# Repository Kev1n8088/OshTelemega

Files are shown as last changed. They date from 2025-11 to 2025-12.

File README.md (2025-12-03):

# Mega3080 v1.0

The Mega3080 FCU is an evolved clone of the Altus Metrum Telemega. Using the same firmware (meaning the same sensor suite), the primary developments are:
- USB-C
- Wago style spring terminals
- Better GPS RF routing, and external GPS antenna
- Companion port with extra UART and space for potential direct Mosaic Integration
- Mag switch with "hard to disarm" feature 
- Slightly smaller (30x80mm instead of 31.25x82.55mm)
- Better reverse polarity protection, including on pyro charges
- Cheaper than purchasing a TeleMega

## Basic Manual

All Wago ports are the same as the Telemega screw terminals, except for the addition of a connector to select between an external switch and the internal mag switch (you can use both!).

To enable the internal mag switch, bridge the terminals marked **MG**. A magnet's **N** pole perpendicular to the top surface magnetic sensor (under the square buzzer) arms the device. 

A fully armed device has the dual-LED next to the mag sensor fully lit (green and red). To begin the disarm process, expose the sensor to a **S** pole, then a **N** pole, and then an **S** pole. This will cycle the LED lights. This feature prevents any risk of disarming from launch towers that may generate magnetic fields.

If a device on the pad has a partially lit LED, the disarm process has started. It is recommended that a disarm and arming cycle be completed to reduce the risk of inadvertent disarm; however, even during the disarm process, the device remains as, if not less, sensitive to stray magnetic fields as industry-standard altimeters.

To use an external switch, simply wire it in series with the terminals marked **SW**. 

If you want an external switch in parallel with the internal mag switch **(NOT RECOMMENDED)** - you can wire both a switch in series with the **SW** terminals, and bridge the **MG** terminals. 

If you want an external switch in series with the internal mag switch **(MAYBE ALRIGHT?)** - you can wire a switch in series with the **MG** terminals. 

To enable GPS operation, connect a standard L1 patch antenna to the rear UFL connector marked L1 GPS. This port supports both passive and active patch antennas. 

Companion and servo connector documentation TBD

See the `flashing.md` file for flashing info. 

## Production
All SMT components can be assembled via JLCPCB.

THT BOM is to be produced soon. 

Use the `jlcpcb/production_files` subdirectory for production files. I do not guarantee that everything will be in stock on JLC, nor do I guarantee that the rotations are correct (they are not, **CHECK VERY CAREFULLY!**).

Recommended configuration is **JLC04161H-7628**. I recommend ENIG, but it's likely not necessary. 

## Notes
Use at your own risk! This device has not been validated as of Dec 2025, and custom production from JLC always carries the risk of QC issues. 

You must provide your own patch antenna (preferably active) to use the GPS

There are a few minor issues known with the v1.0 model: 

- When powered through the mag switch, there is a diode in the path for pyro power. This shouldn't be an issue in practice, but it is technically rated only for 1A continuous. The transient rating is more than enough at 50A, so it's not really a huge issue. There is also a slight voltage drop. Not an issue when the mag switch is bypassed or when a separate pyro battery is used.
- Theoretically, the vertical USB-C Connector is more fragile than a horizontal one - and also harder to solder with a hot air station. Take care when using heavy cables, and if you are concerned, epoxy the connector down.
- Due to a technical oversight, the separate pyro battery capability of the stock telemega, which is rated up to 30v, has to be derated to 12v on the Mega3080. Not sure how many people use a 12+v external pyro battery, but something to be aware of.

The v1.1 release has fixed the USB-C issue; however, the v1.1 device has not been produced yet. Use at your own risk.  

---

**Device Version Last Produced Officially:** v1.0

**Last Updated:** December 2025  

**Written by:** Kevin Zheng (Kev1n8088)

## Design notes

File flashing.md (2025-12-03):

# Building TeleMega v7.0 Bootloader on Windows

This guide shows how to build the bootloader firmware for TeleMega v7.0 using Windows Subsystem for Linux (WSL). After the bootloader is installed once via ST-Link, all future firmware updates can be done through AltosUI over USB. 

This procedure should be identical for all other USB-flashed Altus Devices, just with a different ```src``` subdirectory - but this has not been tested by the author. 

## Prerequisites

- Windows 10/11 with WSL support
- ST-Link programmer (for initial bootloader flash only)
- Blank STM32L1 chip on TeleMega v7.0 board
- STM32 ST-Link Utility installed on Windows
- AltOS Software installed
- AltOS Source downloaded - from [here](https://altusmetrum.org/AltOS/)

## Step 1: Install WSL Ubuntu

Open PowerShell as Administrator and run:

```powershell
wsl --install -d Ubuntu-24.04
```

Restart your computer when prompted, then launch Ubuntu from the Start menu and create a user account.

## Step 2: Install Build Dependencies

In the Ubuntu terminal:

```bash
sudo apt update
sudo apt install -y gcc-arm-none-eabi build-essential autoconf automake \
    libtool picolibc-arm-none-eabi default-jdk libjansson-dev nickle
```

## Step 3: Copy Source to WSL

Copy the AltOS source to WSL's native filesystem (required to avoid NTFS permission issues):

```bash
cp -r /mnt/c/Users/<YourUsername>/Desktop/altos-1.9.22 ~/altos-1.9.22
cd ~/altos-1.9.22
```

Replace `<YourUsername>` with your Windows username.

## Step 4: Configure Build System

```bash
./configure --with-arm-cc=arm-none-eabi-gcc
```

This will check for all required dependencies and configure the build system.

## Step 5: Build the Bootloader

```bash
cd src/telemega-v7.0/flash-loader
make
```

The bootloader will be built as:
- `telemega-v7.0-altos-flash-1.9.22.elf` (ELF binary)
- `telemega-v7.0-altos-flash-1.9.22.hex` (Intel HEX format for ST-Link)

Verify the build succeeded:

```bash
ls -lh telemega-v7.0-altos-flash-1.9.22.*
```

You should see both `.elf` and `.hex` files (~4KB each).

## Step 6: Copy Bootloader to Windows

```bash
cp telemega-v7.0-altos-flash-1.9.22.hex /mnt/c/Users/<YourUsername>/Desktop/
```

## Step 7: Flash Bootloader with ST-Link

1. Connect ST-Link programmer to TeleMega v7.0 SWD interface:
   - **SWDIO** → SWDIO
   - **SWCLK** → SWCLK
   - **GND** → GND
   - **3.3V** → 3v3
   - Make sure the board is powered by a seperate power supply as the ST-Link Programmer does not provide power.

2. Open **STM32 ST-Link Utility** on Windows

3. Click **Target → Connect**

4. Click **Target → Program & Verify...**

5. Browse to `telemega-v7.0-altos-flash-1.9.22.hex` on your Desktop

6. Click **Start**

7. Wait for "Verification...OK" message

8. Disconnect ST-Link programmer

## Step 8: Flash Main Firmware via AltosUI

1. Connect TeleMega v7.0 to PC via USB

3. Launch **AltosUI**

4. Click **Flash Image**

5. Select serial port (e.g., COM13)

6. Browse for the Telemega 7.0 flight firmware in the AltosMetrum file directory - look for something named ```telemega-v7.0-1.9.22.ihx``` or similar

7. Click **OK** to flash

8. Wait for completion message

9. Device will reboot into main firmware

## Step 9: Initial Configuration

Conduct the standard initialization procedure in AltOS, including accelerometer calibration - this should clear the "Sensor failure" beeps. Add your callsign, configure deployments, and calibrate the radio (TBD)

## Memory Map Reference

- **Bootloader:** `0x08000000` - `0x08001000` (4KB)
- **Main Firmware:** `0x08001000` - `0x08020000` (124KB)

## Troubleshooting

### Build Errors

**"No JVM files found" during configure:**
- Java is required even though it's not used for bootloader
- Install: `sudo apt install default-jdk`

**Permission denied errors:**
- Ensure source is in `~/altos-1.9.22` (WSL filesystem)
- Don't build from `/mnt/c/` (NTFS mounts have permission issues)

**Missing picolibc:**
- Install: `sudo apt install picolibc-arm-none-eabi`

### Flashing Issues

**ST-Link cannot connect:**
- Check SWD wiring (SWDIO, SWCLK, GND)
- Verify board has power (LED should be on)
- Try "Connect under reset" option in ST-Link Utility

**Device not recognized by AltOS after bootloader flash:**
- Attempt a power cycle. 
- If not functional, do not panic - try to reflash the bootloader **OR:** 
- Follow the recovery procedure of connecting the Companion port CS0 (pin 6) to GND when powering the device on to force it into recovery mode.  

**COM port not visible:**
- Install Altus Metrum drivers (included with AltosUI)
- Check Device Manager for unrecognized devices
- Manually install `altusmetrum.inf` if needed

**Sensor failure beeps (dah dit dit dah):**
- Run accelerometer calibration in AltOS
- If not fixed, confirm all sensors operation in Serial terminal by opening the COM port and sending in the ```?``` command at 115200 baud for the commands required for querying sensors. Note that for some reason this COM port does not show up in the VSCode for some reason - it worked for on PuTTY for the author. 

## Future Firmware Updates

After the bootloader is installed, **ST-Link is no longer needed**. All future updates can be done via USB:

1. Connect device via USB
2. Launch AltosUI
3. Click **Flash Image**
4. Select your device and new firmware file
5. Flash completes automatically

## Notes

- The bootloader only needs to be flashed **once per board**
- Standard `telemega-v7.0` firmware is for normal flight operations
- `telemega-v7.0-seeed` variant is for hardware validation only (requires GPS lock in 10 seconds)
- Always calibrate accelerometer before first flight
- Firmware version 1.9.22 includes Mosaic X5 GPS support (configurable via `c g` command)

## Additional Resources

- AltOS Documentation: https://altusmetrum.org/AltOS/doc/
- Source Repository: https://altusmetrum.org/AltOS/

---

**Version:** 1.9.22  
**Last Updated:** December 2025  
**Target Hardware:** TeleMega v7.0 (STM32L1 series)

**Written by:** Kevin Zheng (Kev1n8088)

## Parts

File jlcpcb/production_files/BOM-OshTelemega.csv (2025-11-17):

Comment | Designator | Footprint | LCSC | Quantity
1.8nF | C27 | C_0402_1005Metric | C107024 | 1
DFLS130L | D1 | D_PowerDI-123 | C110493 | 1
56k | R11,R12 | R_0402_1005Metric | C114756 | 2
1k | R17,R20,R22,R26,R3,R30,R34,R38,R39,R4,R50,R51,R56 | R_0402_1005Metric | C11702 | 13
CC1200 | U8 | QFN-32-1EP_5x5mm_P0.5mm_EP3.45x3.45mm | C122881 | 1
LQG15HS22NG02D | L8 | L_0402_1005Metric | C12670 | 1
BATT | J8 | JST_PH_B2B-PH-K_1x02_P2.00mm_Vertical | C131337 | 1
STM32L151VCTx | U1 | LQFP-100_14x14mm_P0.5mm | C1338621 | 1
5.6k | R46 | R_0402_1005Metric | C137856 | 1
2.49k | R37 | R_0402_1005Metric | C145071 | 1
MCP73831-2-OT | U17 | SOT-23-5 | C14879 | 1
10nF | C22,C33,C35,C43 | C_0402_1005Metric | C15195 | 4
0.1uF | C1,C10,C16,C17,C3,C4,C44,C7,C9 | C_0402_1005Metric | C1525 | 9
100pF | C36 | C_0402_1005Metric | C1546 | 1
8pF | C5,C6 | C_0402_1005Metric | C1549 | 2
10uF | C18 | C_0402_1005Metric | C15525 | 1
6.2pF | C42 | C_0402_1005Metric | C161332 | 1
56pF | C31 | C_0402_1005Metric | C162113 | 1
LQG15HS56NJ02D | L1,L2 | L_0402_1005Metric | C162544 | 2
ECS-160-8-36Q-AES-TR1 | X2 | Crystal_SMD_2520-4Pin_2.5x2.0mm | C1669787 | 1
0.22uF | C13 | C_0402_1005Metric | C16772 | 1
LED_Dual_AAKK | D3,D4,D5 | DualLED0606 | C183840 | 3
BMI088 | U9 | Bosch_LGA-16_4.5x3mm_P0.5mm_LayoutBorder7x1y_ClockwisePinNumbering | C194919 | 1
WE-TVS-82400102 | U2 | SOT-23-6 | C1975330 | 1
MLG1005S43NJTD25 | L7 | L_0402_1005Metric | C2042359 | 1
AO3400A | Q2 | SOT-23 | C20917 | 1
SISB46DN | U20,U22,U23 | PowerPak1212-8-Dual | C22366987 | 3
8.06k | R41 | R_0402_1005Metric | C227258 | 1
4.7uF | C20,C21 | C_0402_1005Metric | C23733 | 2
10R 0.25W | R54 | R_0402_1005Metric | C25077 | 1
18 | R48 | R_0402_1005Metric | C25084 | 1
220 | R5,R6,R7,R8 | R_0402_1005Metric | C25091 | 4
22 | R10,R9 | R_0402_1005Metric | C25092 | 2
CPE-171 | U11 | XDCR_CPT-7502-65-SMT-TR | C25504047 | 1
ABM8W-40.0000MHZ | Y1 | Crystal_SMD_Abracon_ABM8G-4Pin_3.2x2.5mm | C255943 | 1
100k | R13,R14,R23,R27,R31,R35,R44,R49,R52,R53 | R_0402_1005Metric | C25741 | 10
10k | R40,R42,R47 | R_0402_1005Metric | C25744 | 3
12k | R15,R16,R24,R28,R32,R36,R45 | R_0402_1005Metric | C25752 | 7
3.3k | R18,R19,R21,R25,R29,R33 | R_0402_1005Metric | C25890 | 6
5.1k | R1,R2 | R_0402_1005Metric | C25905 | 2
DRV5012AEDMRR | U7 | Texas_X2SON-4-1EP_1.1x1.4mm_P0.5mm_EP0.8x0.6mm | C2655038 | 1
LI0402C221R-10 | FB1 | L_0402_1005Metric | C269768 | 1
9.09k | R43 | R_0402_1005Metric | C274897 | 1
UFL | J5 | U.FL_Molex_MCRF_73412-0110_Vertical | C277719 | 1
TC2185-3.3VxCTTR | U18 | SOT-23-5 | C2798212 | 1
5.1pF | C37,C38,C39 | C_0402_1005Metric | C281761 | 3
USB_C_Receptacle_USB2.0_16P | J4 | USB_C_Receptacle_G-Switch_GT-USB-7051x | C2843970 | 1
SERVOS | J10 | PinHeader_2x03_P1.27mm_Vertical | C2935951 | 1
Conn_02x05_Counter_Clockwise | J9 | PinHeader_2x05_P1.27mm_Vertical | C2935954 | 1
W25Q64JVXGIQ | U19 | DFN_XGIQ TR_WIN | C2940195 | 1
LM293QT | U12,U13,U15 | DFN-8-1EP_2x2mm_P0.5mm_EP0.9x1.6mm | C2970217 | 3
39pF | C40 | C_0402_1005Metric | C327068 | 1
10pF | C25,C26 | C_0402_1005Metric | C32949 | 2
PPS | D6 | LED_0402_1005Metric | C364550 | 1
MMC5983MA | U10 | LGA-16_3x3mm_P0.5mm | C404329 | 1
MAX-M10S | U5 | ublox_MAX | C4153167 | 1
SN74LVC1G80QDCKTQ1 | U21 | SOT-353_SC-70-5 | C473331 | 1
ADXL375 | U3 | LGA-14_3x5mm_P0.8mm_LayoutBorder1x6y | C481898 | 1
1uF | C19,C2,C24,C8 | C_0402_1005Metric | C52923 | 4
LQG15HZ27NJ02D | L3,L4 | L_0402_1005Metric | C560069 | 2
47nF | C11,C12,C14,C15,C28,C29,C30,C32,C34 | C_0402_1005Metric | C576715 | 9
100k | R55 | R_0402_1005Metric | C60491 | 1
MCP130-xxxxTT | U6 | SOT-23 | C625194 | 1
SiA449DJ | Q1,Q3,Q4 | Vishay_PowerPAK_SC70-6L_Single | C727325 | 3
BAT54CW | D2 | SOT-323_SC-70 | C82467 | 1
LQG15HS15NJ02D | L5,L6 | L_0402_1005Metric | C86059 | 2
2.2pF | C41 | C_0402_1005Metric | C88887 | 1
47uF | C23 | C_1206_3216Metric | C96123 | 1
MS5607-02BA | U4 | LGA-8_3x5mm_P1.25mm | C97627 | 1
LQG15HS47NJ02 | FB2 | L_0402_1005Metric | C97998 | 1
RIGHT | J6 | CONN9_250-309_WAG |  | 1
LEFT | J7 | CONN9_250-309_WAG |  | 1
SMA_Edgelaunch | J3 | SMA_Amphenol_132289_EdgeMount |  | 1

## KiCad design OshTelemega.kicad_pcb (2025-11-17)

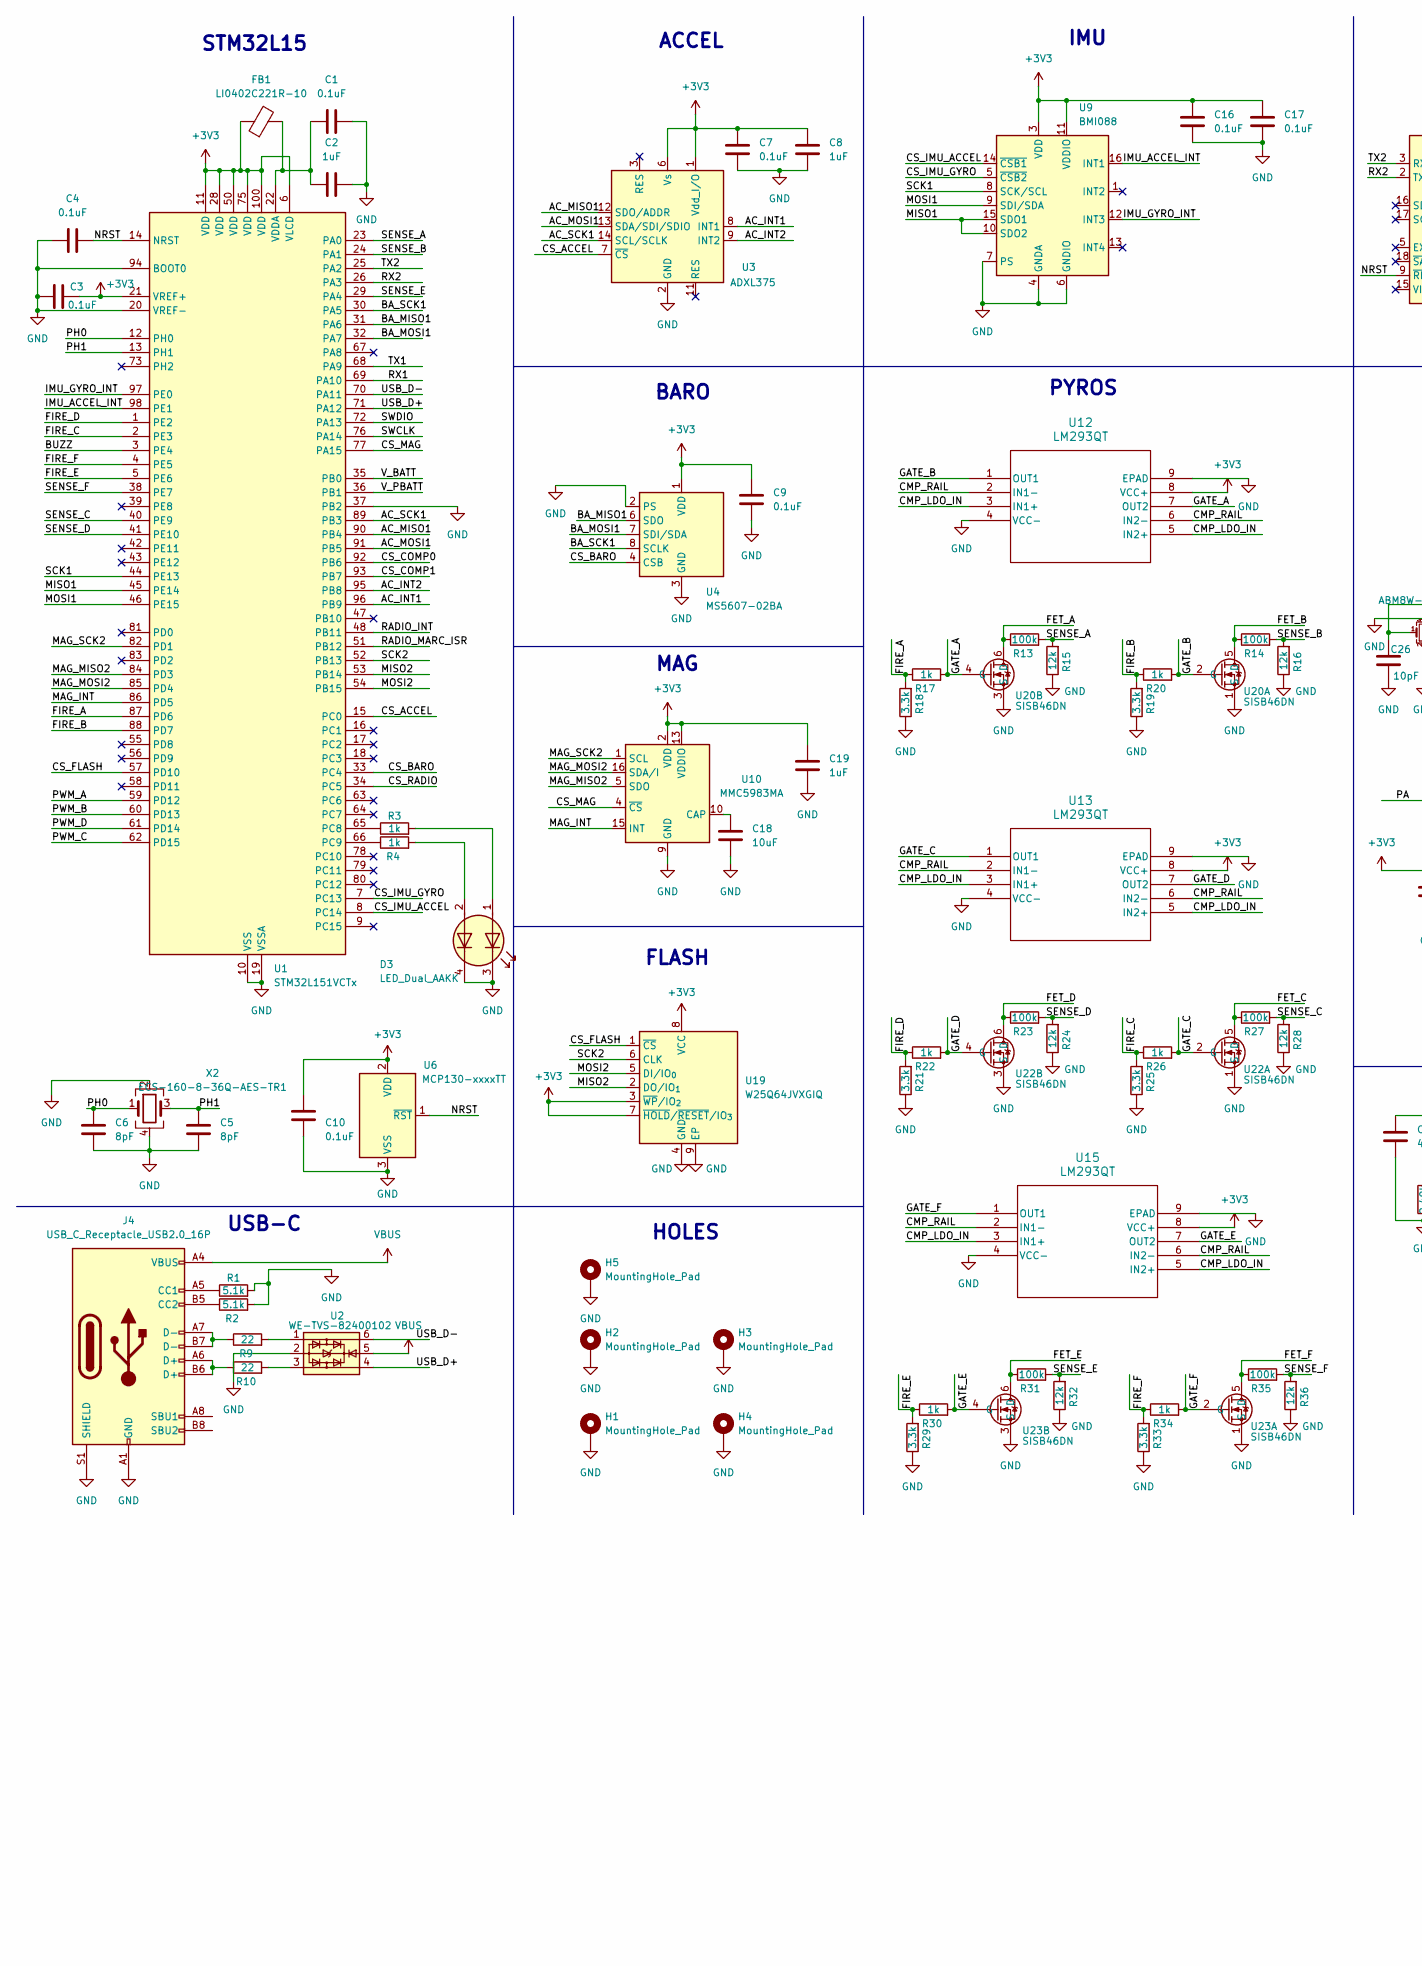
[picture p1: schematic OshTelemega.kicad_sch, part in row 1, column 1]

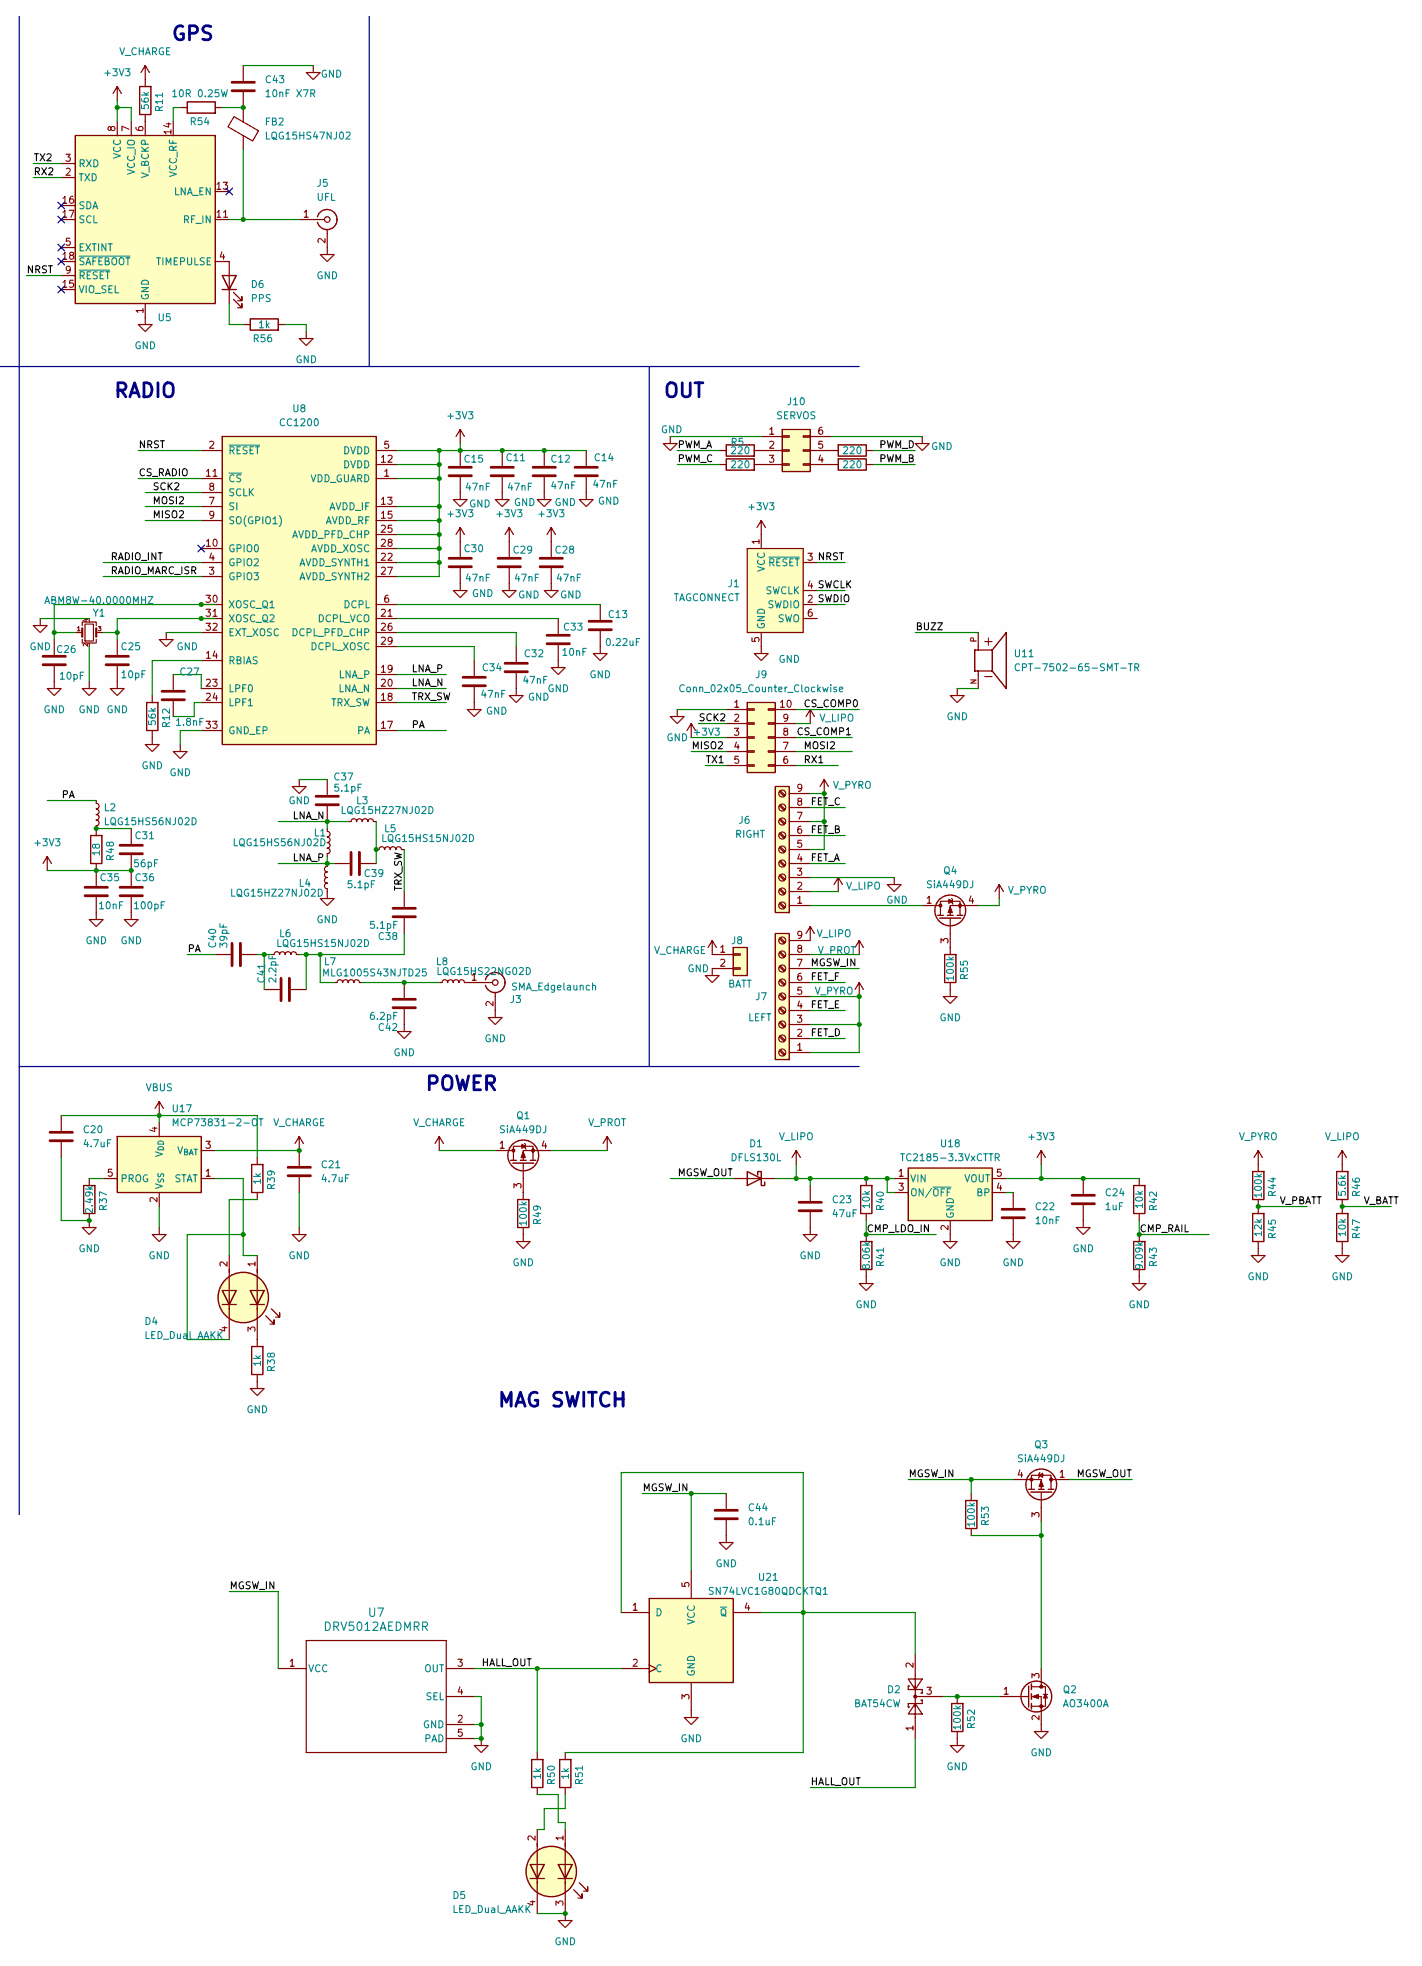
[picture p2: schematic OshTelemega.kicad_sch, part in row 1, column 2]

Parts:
C1, C3, C4, C7, C9, C10, C16, C17, C44: 0.1uF; C_0402_1005Metric
C2, C8, C19, C24: 1uF; C_0402_1005Metric
C5, C6: 8pF; C_0402_1005Metric
C11, C12, C14, C15, C28, C29, C30, C32, C34: 47nF; C_0402_1005Metric
C13: 0.22uF; C_0402_1005Metric
C18: 10uF; C_0402_1005Metric
C20, C21: 4.7uF; C_0402_1005Metric
C22, C33, C35: 10nF; C_0402_1005Metric
C23: 47uF; C_1206_3216Metric
C25, C26: 10pF; C_0402_1005Metric
C27: 1.8nF; C_0402_1005Metric
C31: 56pF; C_0402_1005Metric
C36: 100pF; C_0402_1005Metric
C37, C38, C39: 5.1pF; C_0402_1005Metric
C40: 39pF; C_0402_1005Metric
C41: 2.2pF; C_0402_1005Metric
C42: 6.2pF; C_0402_1005Metric
C43: 10nF X7R; C_0402_1005Metric
D1: DFLS130L; D_PowerDI-123
D2: BAT54CW; SOT-323_SC-70
D3, D4, D5: LED_Dual_AAKK; DualLED0606
D6: PPS; LED_0402_1005Metric
FB1: LI0402C221R-10; L_0402_1005Metric
FB2: LQG15HS47NJ02; L_0402_1005Metric
H1, H2, H3, H4, H5: MountingHole_Pad; MountingHole_3.2mm_M3_DIN965_Pad
J1: TAGCONNECT; Tag-Connect_TC2030-IDC-NL_2x03_P1.27mm_Vertical
J3: SMA_Edgelaunch; SMA_Amphenol_132289_EdgeMount
J4: USB_C_Receptacle_USB2.0_16P; USB_C_Receptacle_G-Switch_GT-USB-7051x
J5: UFL; U.FL_Molex_MCRF_73412-0110_Vertical
J6: RIGHT; CONN9_250-309_WAG
J7: LEFT; CONN9_250-309_WAG
J8: BATT; JST_PH_B2B-PH-K_1x02_P2.00mm_Vertical
J9: Conn_02x05_Counter_Clockwise; PinHeader_2x05_P1.27mm_Vertical
J10: SERVOS; PinHeader_2x03_P1.27mm_Vertical
L1, L2: LQG15HS56NJ02D; L_0402_1005Metric
L3, L4: LQG15HZ27NJ02D; L_0402_1005Metric
L5, L6: LQG15HS15NJ02D; L_0402_1005Metric
L7: MLG1005S43NJTD25; L_0402_1005Metric
L8: LQG15HS22NG02D; L_0402_1005Metric
Q1, Q3, Q4: SiA449DJ; Vishay_PowerPAK_SC70-6L_Single
Q2: AO3400A; SOT-23
R1, R2: 5.1k; R_0402_1005Metric
R3, R4, R17, R20, R22, R26, R30, R34, R38, R39, R50, R51, R56: 1k; R_0402_1005Metric
R5, R6, R7, R8: 220; R_0402_1005Metric
R9, R10: 22; R_0402_1005Metric
R11, R12: 56k; R_0402_1005Metric
R13, R14, R23, R27, R31, R35, R44, R49, R52, R53, R55: 100k; R_0402_1005Metric
R15, R16, R24, R28, R32, R36, R45: 12k; R_0402_1005Metric
R18, R19, R21, R25, R29, R33: 3.3k; R_0402_1005Metric
R37: 2.49k; R_0402_1005Metric
R40, R42, R47: 10k; R_0402_1005Metric
R41: 8.06k; R_0402_1005Metric
R43: 9.09k; R_0402_1005Metric
R46: 5.6k; R_0402_1005Metric
R48: 18; R_0402_1005Metric
R54: 10R 0.25W; R_0402_1005Metric
U1: STM32L151VCTx; LQFP-100_14x14mm_P0.5mm
U2: WE-TVS-82400102; SOT-23-6
U3: ADXL375; LGA-14_3x5mm_P0.8mm_LayoutBorder1x6y
U4: MS5607-02BA; LGA-8_3x5mm_P1.25mm
U5: MAX-M10S; ublox_MAX
U6: MCP130-xxxxTT; SOT-23
U7: DRV5012AEDMRR; Texas_X2SON-4-1EP_1.1x1.4mm_P0.5mm_EP0.8x0.6mm
U8: CC1200; QFN-32-1EP_5x5mm_P0.5mm_EP3.45x3.45mm
U9: BMI088; Bosch_LGA-16_4.5x3mm_P0.5mm_LayoutBorder7x1y_ClockwisePinNu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
U10: MMC5983MA; LGA-16_3x3mm_P0.5mm
U11: CPT-7502-65-SMT-TR; XDCR_CPT-7502-65-SMT-TR; PARTREV 1.0
U12, U13, U15: LM293QT; DFN-8-1EP_2x2mm_P0.5mm_EP0.9x1.6mm
U17: MCP73831-2-OT; SOT-23-5
U18: TC2185-3.3VxCTTR; SOT-23-5
U19: W25Q64JVXGIQ; DFN_XGIQ TR_WIN
U20, U22, U23: SISB46DN; PowerPak1212-8-Dual
U21: SN74LVC1G80QDCKTQ1; SOT-353_SC-70-5
X2: ECS-160-8-36Q-AES-TR1; Crystal_SMD_2520-4Pin_2.5x2.0mm
Y1: ABM8W-40.0000MHZ; Crystal_SMD_Abracon_ABM8G-4Pin_3.2x2.5mm

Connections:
+3V3: C3.2, C7.2, C8.2, C9.2, C10.2, C11.2, C12.2, C14.2, C15.2, C16.2, C17.2, C19.2, C24.2, C28.2, C29.2, C30.2, C31.1, C35.2, C36.2, FB1.1, J1.1 (VCC), J9.3, R42.2, R48.1, U1.6 (VLCD), U1.11 (VDD), U1.21 (VREF+), U1.28 (VDD), U1.50 (VDD), U1.75 (VDD), U1.100 (VDD), U3.1 (Vdd_I/O), U3.6 (Vs), U4.1 (VDD), U5.7 (VCC_IO), U5.8 (VCC), U6.2 (VDD), U8.1 (VDD_GUARD), U8.5 (DVDD), U8.12 (DVDD), U8.13 (AVDD_IF), U8.15 (AVDD_RF), U8.22 (AVDD_SYNTH1), U8.25 (AVDD_PFD_CHP), U8.27 (AVDD_SYNTH2), U8.28 (AVDD_XOSC), U9.3 (VDD), U9.11 (VDDIO), U10.2 (VDD), U10.13 (VDDIO), U12.8 (VCC+), U13.8 (VCC+), U15.8 (VCC+), U18.5 (VOUT), U19.3 (~WP/IO_{2}), U19.7 (~HOLD/~RESET/IO_{3}), U19.8 (VCC)
/AC_INT1: U1.96 (PB9), U3.8 (INT1)
/AC_INT2: U1.95 (PB8), U3.9 (INT2)
/AC_MISO1: U1.90 (PB4), U3.12 (SDO/ADDR)
/AC_MOSI1: U1.91 (PB5), U3.13 (SDA/SDI/SDIO)
/AC_SCK1: U1.89 (PB3), U3.14 (SCL/SCLK)
/BA_MISO1: U1.31 (PA6), U4.6 (SDO)
/BA_MOSI1: U1.32 (PA7), U4.7 (SDI/SDA)
/BA_SCK1: U1.30 (PA5), U4.8 (SCLK)
/BUZZ: U1.3 (PE4), U11.P
/CMP_LDO_IN: R40.1, R41.2, U12.3 (IN1+), U12.5 (IN2+), U13.3 (IN1+), U13.5 (IN2+), U15.3 (IN1+), U15.5 (IN2+)
/CMP_RAIL: R42.1, R43.2, U12.2 (IN1-), U12.6 (IN2-), U13.2 (IN1-), U13.6 (IN2-), U15.2 (IN1-), U15.6 (IN2-)
/CS_ACCEL: U1.15 (PC0), U3.7 (~CS)
/CS_BARO: U1.33 (PC4), U4.4 (CSB), U4.5 (CSB)
/CS_COMP0: J9.10, U1.92 (PB6)
/CS_COMP1: J9.8, U1.93 (PB7)
/CS_FLASH: U1.57 (PD10), U19.1 (~CS)
/CS_IMU_ACCEL: U1.8 (PC14), U9.14 (~CSB1)
/CS_IMU_GYRO: U1.7 (PC13), U9.5 (~CSB2)
/CS_MAG: U1.77 (PA15), U10.4 (~CS)
/CS_RADIO: U1.34 (PC5), U8.11 (~CS)
/FET_A: J6.4, R13.1, U20.6 (D)
/FET_B: J6.6, R14.1, U20.5 (D)
/FET_C: J6.8, R27.1, U22.5 (D)
/FET_D: J7.2, R23.1, U22.6 (D)
/FET_E: J7.4, R31.1, U23.6 (D)
/FET_F: J7.6, R35.1, U23.5 (D)
/FIRE_A: R17.1, R18.2, U1.87 (PD6)
/FIRE_B: R19.2, R20.1, U1.88 (PD7)
/FIRE_C: R25.2, R26.1, U1.2 (PE3)
/FIRE_D: R21.2, R22.1, U1.1 (PE2)
/FIRE_E: R29.2, R30.1, U1.5 (PE6)
/FIRE_F: R33.2, R34.1, U1.4 (PE5)
/GATE_A: R17.2, U12.7 (OUT2), U20.4 (G)
/GATE_B: R20.2, U12.1 (OUT1), U20.2 (G)
/GATE_C: R26.2, U13.1 (OUT1), U22.2 (G)
/GATE_D: R22.2, U13.7 (OUT2), U22.4 (G)
/GATE_E: R30.2, U15.7 (OUT2), U23.4 (G)
/GATE_F: R34.2, U15.1 (OUT1), U23.2 (G)
/HALL_OUT: D2.1, R50.2, U7.3 (OUT), U21.2 (C)
/IMU_ACCEL_INT: U1.98 (PE1), U9.16 (INT1)
/IMU_GYRO_INT: U1.97 (PE0), U9.12 (INT3)
/LNA_N: C37.1, L1.1, L3.1, U8.20 (LNA_N)
/LNA_P: C39.2, L1.2, L4.2, U8.19 (LNA_P)
/MAG_INT: U1.86 (PD5), U10.15 (INT)
/MAG_MISO2: U1.84 (PD3), U10.5 (SDO)
/MAG_MOSI2: U1.85 (PD4), U10.16 (SDA/I)
/MAG_SCK2: U1.82 (PD1), U10.1 (SCL)
/MGSW_IN: C44.2, J7.7, Q3.4 (S), R53.2, U7.1 (VCC), U21.5 (VCC)
/MGSW_OUT: D1.2 (A), Q3.1 (D)
/MISO1: U1.45 (PE14), U9.10 (SDO2), U9.15 (SDO1)
/MISO2: J9.4, U1.53 (PB14), U8.9 (SO(GPIO1)), U19.2 (DO/IO_{1})
/MOSI1: U1.46 (PE15), U9.9 (SDI/SDA)
/MOSI2: J9.7, U1.54 (PB15), U8.7 (SI), U19.5 (DI/IO_{0})
/NRST: C4.2, J1.3 (~RESET), U1.14 (NRST), U5.9 (~RESET), U6.1 (~RST), U8.2 (~RESET)
/PA: C40.2, L2.1, U8.17 (PA)
/PH0: C6.2, U1.12 (PH0), X2.1
/PH1: C5.2, U1.13 (PH1), X2.3
/PWM_A: R5.1, U1.59 (PD12)
/PWM_B: R6.1, U1.60 (PD13)
/PWM_C: R7.1, U1.62 (PD15)
/PWM_D: R8.1, U1.61 (PD14)
/RADIO_INT: U1.48 (PB11), U8.4 (GPIO2)
/RADIO_MARC_ISR: U1.51 (PB12), U8.3 (GPIO3)
/RX1: J9.6, U1.69 (PA10)
/RX2: U1.26 (PA3), U5.2 (TXD)
/SCK1: U1.44 (PE13), U9.8 (SCK/SCL)
/SCK2: J9.2, U1.52 (PB13), U8.8 (SCLK), U19.6 (CLK)
/SENSE_A: R13.2, R15.2, U1.23 (PA0)
/SENSE_B: R14.2, R16.2, U1.24 (PA1)
/SENSE_C: R27.2, R28.2, U1.40 (PE9)
/SENSE_D: R23.2, R24.2, U1.41 (PE10)
/SENSE_E: R31.2, R32.2, U1.29 (PA4)
/SENSE_F: R35.2, R36.2, U1.38 (PE7)
/SWCLK: J1.4 (SWCLK), U1.76 (PA14)
/SWDIO: J1.2 (SWDIO), U1.72 (PA13)
/TRX_SW: C38.1, L5.2, U8.18 (TRX_SW)
/TX1: J9.5, U1.68 (PA9)
/TX2: U1.25 (PA2), U5.3 (RXD)
/USB_D+: U1.71 (PA12), U2.4
/USB_D-: U1.70 (PA11), U2.6
/V_BATT: R46.1, R47.2, U1.35 (PB0)
/V_PBATT: R44.1, R45.2, U1.36 (PB1)
GND: C1.2, C2.2, C3.1, C4.1, C5.1, C6.1, C7.1, C8.1, C9.1, C10.1, C11.1, C12.1, C13.1, C14.1, C15.1, C16.1, C17.1, C18.1, C19.1, C20.1, C21.1, C22.1, C23.1, C24.1, C25.1, C26.1, C28.1, C29.1, C30.1, C32.1, C33.1, C34.1, C35.1, C36.1, C37.2, C42.2, C43.2, C44.1, D3.3 (K1), D3.4 (K2), D5.3 (K1), D5.4 (K2), H1.1, H2.1, H3.1, H4.1, H5.1, J1.5 (GND), J3.2 (Ext), J4.A1 (GND), J4.A12 (GND), J4.B1 (GND), J4.B12 (GND), J4.S1 (SHIELD), J5.2 (Ext), J6.3, J8.2, J9.1, J10.1, J10.6, L4.1, Q2.2 (S), R1.2, R2.2, R12.1, R15.1, R16.1, R18.1, R19.1, R21.1, R24.1, R25.1, R28.1, R29.1, R32.1, R33.1, R36.1, R37.1, R38.1, R41.1, R43.1, R45.1, R47.1, R49.1, R52.1, R55.1, R56.2, U1.10 (VSS), U1.19 (VSSA), U1.20 (VREF-), U1.27 (VSS), U1.37 (PB2), U1.49 (VSS), U1.74 (VSS), U1.94 (BOOT0), U1.99 (VSS), U2.2, U3.2 (GND), U3.4 (GND), U3.5 (GND), U4.2 (PS), U4.3 (GND), U5.1 (GND), U5.10 (GND), U5.12 (GND), U6.3 (VSS), U7.2 (GND), U7.4 (SEL), U7.5 (PAD), U8.32 (EXT_XOSC), U8.33 (GND_EP), U9.2 (GNDA), U9.4 (GNDA), U9.6 (GNDIO), U9.7 (PS), U10.9 (GND), U10.11 (GND), U11.N, U12.4 (VCC-), U12.9 (EPAD), U13.4 (VCC-), U13.9 (EPAD), U15.4 (VCC-), U15.9 (EPAD), U17.2 (V_{SS}), U18.2 (GND), U19.4 (GND), U19.9 (EP), U20.1 (S), U20.3 (S), U21.3 (GND), U22.1 (S), U22.3 (S), U23.1 (S), U23.3 (S), X2.2, X2.4, Y1.2, Y1.4
unnamed: C31.2, L2.2, R48.2
unnamed: C38.2, C41.1, L6.2, L7.1
unnamed: C39.1, L3.2, L5.1
unnamed: C40.1, C41.2, L6.1
unnamed: C42.1, L7.2, L8.1
unnamed: C43.1, FB2.2, R54.2
unnamed: D3.1 (A1), R3.2
unnamed: D3.2 (A2), R4.2
unnamed: D4.1 (A1), D4.4 (K2), U17.1 (STAT)
unnamed: D4.2 (A2), R39.1
unnamed: D4.3 (K1), R38.2
unnamed: D5.1 (A1), R50.1
unnamed: D5.2 (A2), R51.1
unnamed: D6.2 (A), U5.4 (TIMEPULSE)
unnamed: D6.1 (K), R56.1
unnamed: J3.1 (In), L8.2
unnamed: J4.A5 (CC1), R1.1
unnamed: J4.B5 (CC2), R2.1
unnamed: J4.A6 (D+), J4.B6 (D+), R10.1
unnamed: J4.A7 (D-), J4.B7 (D-), R9.1
unnamed: FB2.1, J5.1 (In), U5.11 (RF_IN)
unnamed: J6.1, Q4.1 (D)
unnamed: J10.2, R5.2
unnamed: J10.3, R7.2
unnamed: J10.4, R6.2
unnamed: J10.5, R8.2
unnamed: Q1.3 (G), R49.2
unnamed: Q2.3 (D), Q3.3 (G), R53.1
unnamed: D2.3, Q2.1 (G), R52.2
unnamed: Q4.3 (G), R55.2
unnamed: R9.2, U2.1
unnamed: R10.2, U2.3
unnamed: R3.1, U1.65 (PC8)
unnamed: R4.1, U1.66 (PC9)
unnamed: C1.1, C2.1, FB1.2, U1.22 (VDDA)
unnamed: R54.1, U5.14 (VCC_RF)
unnamed: R11.1, U5.6 (V_BCKP)
unnamed: C13.2, U8.6 (DCPL)
unnamed: C32.2, U8.26 (DCPL_PFD_CHP)
unnamed: C33.2, U8.21 (DCPL_VCO)
unnamed: C34.2, U8.29 (DCPL_XOSC)
unnamed: C27.2, U8.23 (LPF0)
unnamed: C27.1, U8.24 (LPF1)
unnamed: R12.2, U8.14 (RBIAS)
unnamed: C26.2, U8.30 (XOSC_Q1), Y1.1
unnamed: C25.2, U8.31 (XOSC_Q2), Y1.3
unnamed: C18.2, U10.10 (CAP)
unnamed: R37.2, U17.5 (PROG)
unnamed: C22.2, U18.4 (BP)
unnamed: D2.2, R51.2, U21.1 (D), U21.4 (~Q)
VBUS: C20.2, J4.A4 (VBUS), J4.A9 (VBUS), J4.B4 (VBUS), J4.B9 (VBUS), R39.2, U2.5, U17.4 (V_{DD})
V_CHARGE: C21.2, J8.1, Q1.1 (D), R11.2, U17.3 (V_{BAT})
V_LIPO: C23.2, D1.1 (K), J6.2, J7.9, J9.9, R40.2, R46.2, U18.1 (VIN), U18.3 (ON/~OFF)
V_PROT: J7.8, Q1.4 (S)
V_PYRO: J6.5, J6.7, J6.9, J7.1, J7.3, J7.5, Q4.4 (S), R44.2

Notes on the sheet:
HOLES
MAG SWITCH
BARO
STM32L15
USB-C
MAG
ACCEL
GPS
RADIO
IMU
PYROS
OUT
FLASH
POWER

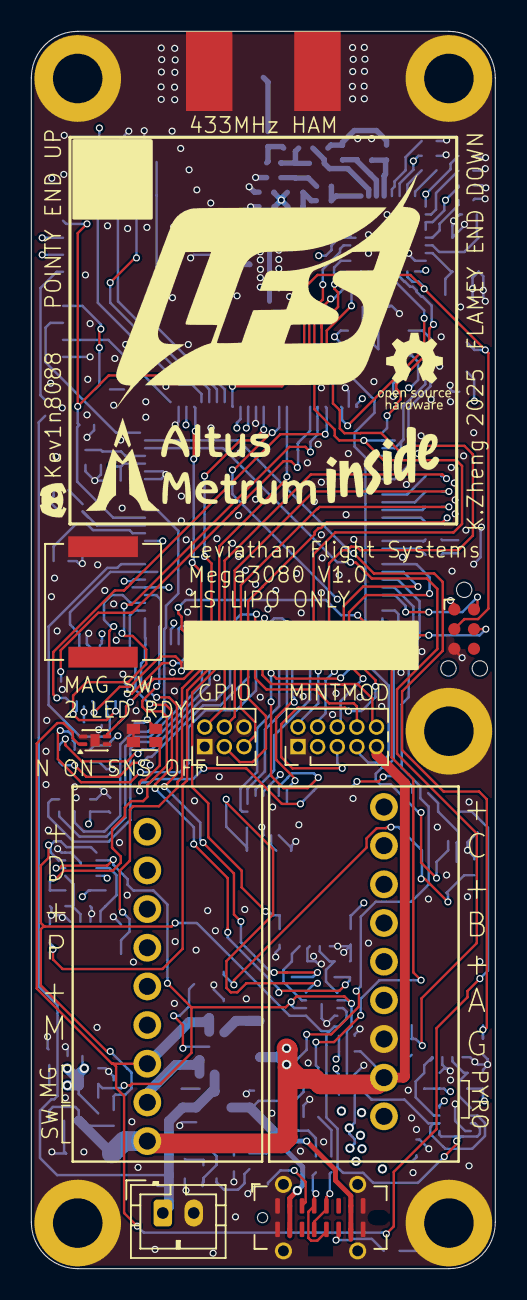
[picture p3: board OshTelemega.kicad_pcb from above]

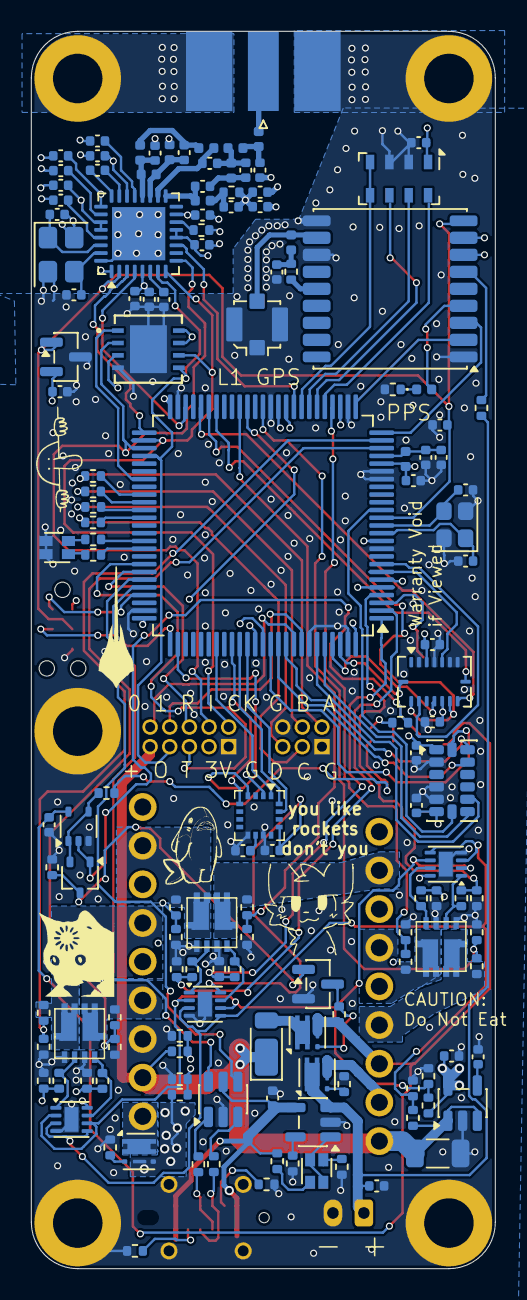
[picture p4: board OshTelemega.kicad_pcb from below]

Board: 4 copper layers, 30.0 x 80.0 mm, 157 parts (142 on the bottom side), 139 nets.

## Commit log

2025-10-08 v0.1 done. Redesigning for potential mosaic integration
    [OshTelemega.kicad_pcb, OshTelemega.kicad_sch]
2025-10-09 before adding 10 pin companion
    [OshTelemega.kicad_pcb, OshTelemega.kicad_sch]
2025-10-09 v0.2 done - just needs review and silkscreens
    [OshTelemega.kicad_pcb, OshTelemega.kicad_sch]
2025-10-09 some jlc manufacturing considerations
    [BOM-OshTelemega.csv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]
2025-10-09 fixed wrong orientation on mag switch mosfet
    [OshTelemega.kicad_pcb, OshTelemega.kicad_sch]
2025-10-09 added pyro rp protection
    [OshTelemega.kicad_pcb, OshTelemega.kicad_sch]
2025-10-10 expanded SMA connector and added some more silkscreens
    [OshTelemega.kicad_pcb]
2025-10-11 finished silkscreen edits. Switching branches to work on JLC DRC
    [OshTelemega.kicad_pcb]
2025-10-11 drc changes and more ground stitching
    [BOM-OshTelemega.csv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]
2025-10-11 minor impedance tune due to new pour clearance
    [OshTelemega.kicad_pcb]
2025-10-13 minor changes
    [BOM-OshTelemega.csv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]
2025-10-13 changes to vias and silkscreens
    [OshTelemega.kicad_pcb]
2025-10-13 resolved drc, added buzzer, and PPS led
    [OshTelemega.kicad_pcb, OshTelemega.kicad_sch]
2025-10-13 silkscreen memes
    [OshTelemega.kicad_pcb]
2025-10-14 tunes for production run 1
    [BOM-OshTelemega.csv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]
2025-11-17 v1.0 production variant
    [BOM-OshTelemega.csv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]
